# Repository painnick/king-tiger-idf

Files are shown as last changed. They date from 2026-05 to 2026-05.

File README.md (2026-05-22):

# RC 탱크 프로젝트

Bluepad32를 이용한 게임패드 조작 RC 탱크입니다. ESP32-IDF(v5.4.3) 기반으로 개발되었습니다.

## 주요 기능

- **게임패드 연결**: Bluepad32를 통한 블루투스 게임패드 연결 및 상태 LED/진동 피드백
- **트랙 제어**: 좌측 스틱 Y축(좌측 트랙), 우측 스틱 Y축(우측 트랙) 독립 제어 (DRV8833, MCPWM)
- **터렛 제어**: D-PAD 좌우로 터렛 회전 (DRV8833, MCPWM, 최대 속도 100% 듀티)
- **포 마운트 제어**: D-PAD 상하로 포신 상하 이동 (SG90 서보, 80~110도, 초당 10도)
- **포신 발사**: B 버튼 클릭 시 포신 반동(서보 0->60->0), LED 점등, 발사 효과음 및 게임패드 진동 발생 (트랙 후진 반동 200ms 동기화)
- **기관총 발사**: A 버튼 클릭 시 기관총 LED 깜빡임(500ms), 효과음 및 게임패드 진동 발생 (반응성 개선을 위해 지연 시간 300ms로 단축)
- **헤드라이트**: Y 버튼으로 헤드라이트 ON/OFF 토글
- **볼륨 조절**: L1 버튼으로 감소, R1 버튼으로 증가 (NVS 저장, 10-30 범위)
- **대기 상태 알림**: 게임패드 연결 전/해제 후에는 30초마다 엔진 IDLE 효과음을 1회 재생하여 상태 알림 (연결 중에는 IDLE 소리 중지)
- **설정 초기화**: Select + Start 버튼을 3초간 누르면 볼륨 설정 초기화 및 재시작

## 하드웨어 구성

### ESP32 핀 맵

| ESP32 핀 | 기능 | 설명 |
| :--- | :--- | :--- |
| **GPIO 4** | 후미등 LED | Backlight |
| **GPIO 5** | 헤드라이트 LED | Headlight (Y 버튼 토글) |
| **GPIO 13** | 포 마운트 서보 | SG90 서보 - 포신 상하 이동 (80~110도) |
| **GPIO 16** | 기관총 LED | MG LED (A 버튼 클릭 시 깜빡임) |
| **GPIO 17** | 포신 LED | Gun LED (B 버튼 클릭 시 점등) |
| **GPIO 21** | 터렛 IN2 | DRV8833 - 터렛 회전 (MCPWM) |
| **GPIO 22** | 터렛 IN1 | DRV8833 - 터렛 회전 (MCPWM) |
| **GPIO 23** | 사운드 TX | DFPlayer Mini UART TX |
| **GPIO 25** | 우측 트랙 IN2 | DRV8833 - 우측 트랙 (MCPWM) |
| **GPIO 26** | 좌측 트랙 IN2 | DRV8833 - 좌측 트랙 (MCPWM) |
| **GPIO 27** | 좌측 트랙 IN1 | DRV8833 - 좌측 트랙 (MCPWM) |
| **GPIO 32** | 포신 서보 | 포신 반동 (Recoil) 제어 |
| **GPIO 33** | 우측 트랙 IN1 | DRV8833 - 우측 트랙 (MCPWM) |

### 모터 드라이버 (DRV8833) 연결

#### 트랙 드라이버
- **AIN (27, 26)**: 좌측 트랙 모터 (MCPWM)
- **BIN (33, 25)**: 우측 트랙 모터 (MCPWM)

#### 터렛 드라이버
- **AIN (22, 21)**: 터렛 회전 모터 (MCPWM, 최대 속도 100% 듀티)

### 서보 모터
- **GPIO 32**: 포신 반동 서보 (B 버튼 시 0도 -> 60도 -> 0도 동작)
- **GPIO 13**: 포 마운트 서보 SG90 (D-PAD 상하, 80~110도 범위, 초기 90도)

### 사운드 모듈 (DFPlayer Mini)
- **TX (GPIO 23)**: 모듈의 RX 핀에 연결하여 UART 제어 (9600bps)
- **RX (NC)**: 현재 수신 핀이 연결되지 않아 모듈 피드백(재생 종료 알림 등) 대신 타이머/하드웨어 루프 명령어로 상태 제어

---

## 게임패드 조작법

| 조작 | 기능 | 상세 동작 |
| :--- | :--- | :--- |
| **좌측 스틱 Y** | 좌측 트랙 | 위(전진), 아래(후진) |
| **우측 스틱 Y** | 우측 트랙 | 위(전진), 아래(후진) |
| **D-PAD 좌/우** | 터렛 회전 | 좌우 회전 (MCPWM, 최대 속도) |
| **D-PAD 상/하** | 포 마운트 | 상하 이동 (SG90 서보, 80~110도) |
| **A 버튼** | 기관총 발사 | 효과음 재생 + MG LED 깜빡임 |
| **B 버튼** | 주포 발사 | 효과음 재생 + Gun LED 점등 + 서보 반동 |
| **Y 버튼** | 헤드라이트 | ON / OFF 토글 |
| **L1 / R1** | 볼륨 조절 | 볼륨 감소 / 증가 (NVS 자동 저장) |
| **Select + Start** | 시스템 초기화 | 3초간 입력 시 설정 초기화 및 재부팅 |

---

## 소프트웨어 구조

### 주요 컴포넌트 (`components/rctank/`)
- `rctank_motor`: MCPWM을 이용한 트랙 및 터렛 제어
- `rctank_servo`: LEDC를 이용한 포신 반동 서보 및 포 마운트(SG90) 서보 제어
- `rctank_led`: 각종 LED 상태 제어
- `rctank_dfplayer`: DFPlayer Mini 제어 및 효과음 재생
- `rctank_storage`: NVS를 이용한 볼륨 및 설정값 저장

### 플랫폼 로직 (`main/my_flatform.c`)
- Bluepad32 이벤트 핸들링 및 게임패드 입력 맵핑
- 발사 시퀀스 지연 보정 (Sound 재생 시점과 하드웨어 동작 동기화)

## 개발 환경 설정

1. **ESP-IDF v5.4.3** 설치
2. 프로젝트 루트의 `env.bat`를 실행하여 환경 변수 설정 (Windows)
3. `idf.py build` 명령으로 컴파일
4. `idf.py flash monitor` 명령으로 업로드 및 로그 확인

## 라이센스
MIT License

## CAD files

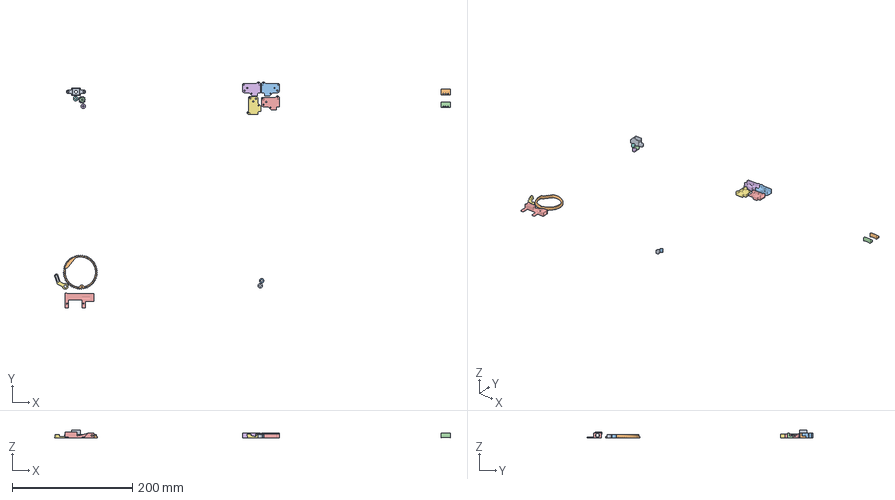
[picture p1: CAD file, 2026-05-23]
3dp/King Tiger.3mf
657.7 x 376.0 x 14.0 mm
Turret Motor Guide v3_1
Turret Gear
Sproket Spacer v3_1
Turret Combined.step
Cannon Guide
Turret Motor Guide v3_2
Mount Motor Horm.step
Turret Motor Guide v3_3
Sproket Spacer v3_2
Locker v1_1
Locker v1_2
Component1(Mirror)_1
Component1(Mirror)_2

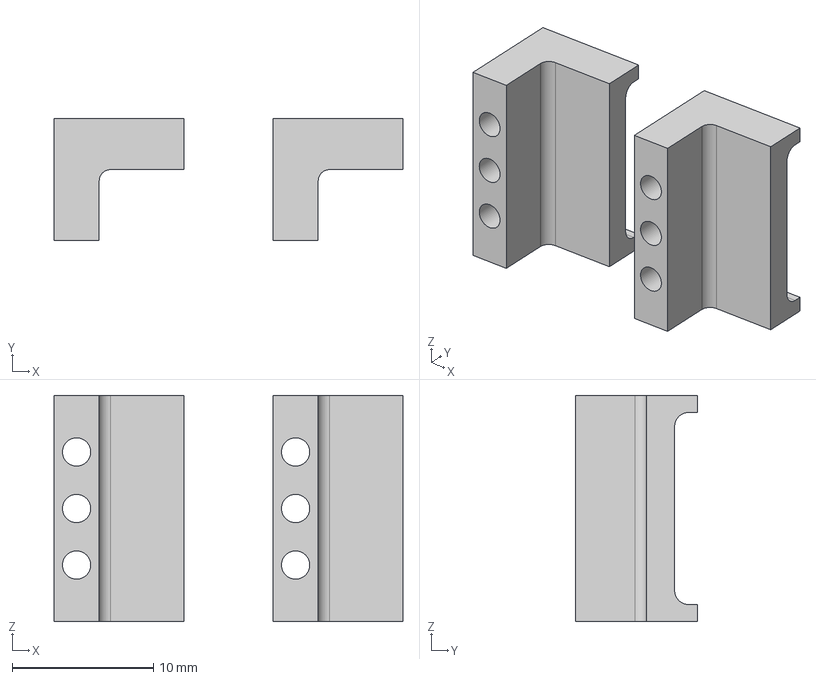
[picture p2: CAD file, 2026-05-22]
3dp/Locker.step
24.7 x 8.60 x 16.0 mm

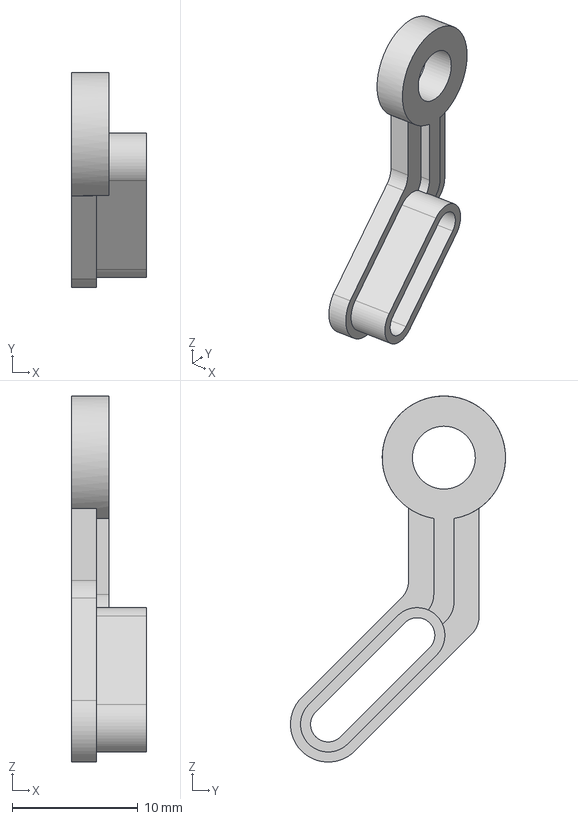
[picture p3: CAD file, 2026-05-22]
3dp/Mount Motor Horn.step
6.00 x 17.1 x 29.1 mm

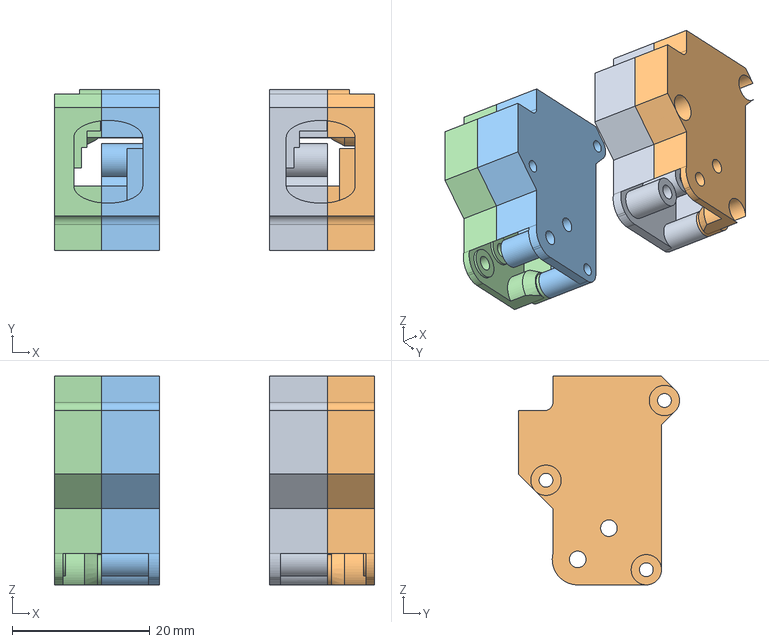
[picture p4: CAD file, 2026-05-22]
3dp/Gearbox2.step
46.4 x 23.4 x 30.3 mm
Component1(Mirror)

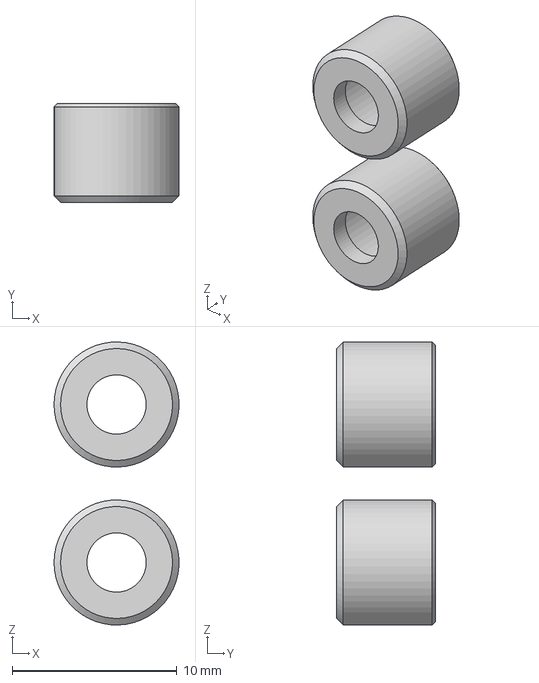
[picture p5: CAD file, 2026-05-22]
3dp/Sproket Spacer.step
7.59 x 6.00 x 17.2 mm

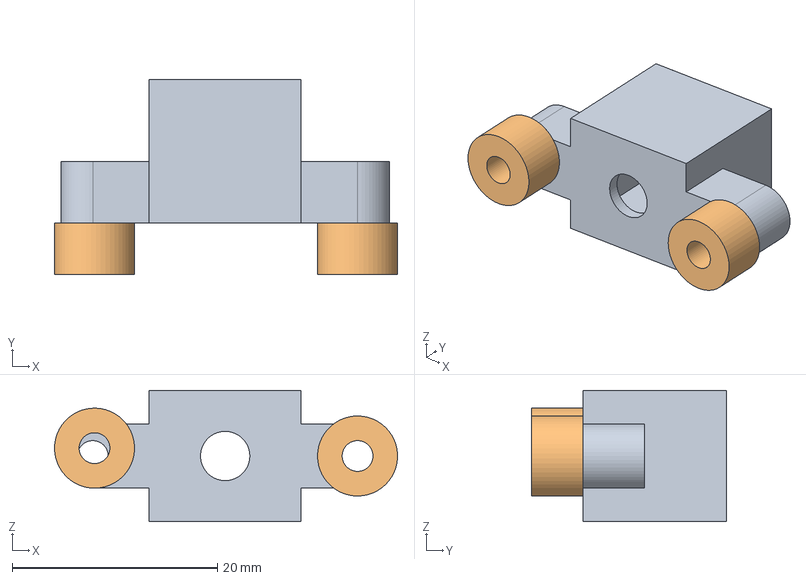
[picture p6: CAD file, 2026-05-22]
3dp/Turret Motor Guide.step
33.4 x 19.0 x 12.8 mm

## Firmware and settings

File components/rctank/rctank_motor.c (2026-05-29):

/**
 * @file rctank_motor.c
 * @brief RC Tank MCPWM 트랙/터렛 제어
 */
#include "rctank_motor.h"
#include "rctank_pins.h"

#include "driver/mcpwm_prelude.h"
#include "esp_log.h"
#include "esp_check.h"

#include "freertos/FreeRTOS.h"
#include "freertos/task.h"
#include "freertos/semphr.h"

static const char *TAG = "rctank_motor";

#define MCPWM_FREQ_HZ          (20000)
#define MCPWM_RESOLUTION_HZ   (1000000)
#define MCPWM_PERIOD_TICKS    (MCPWM_RESOLUTION_HZ / MCPWM_FREQ_HZ)

/* 스틱 범위 ±512 → 듀티 비율 (0~100%) */
#define AXIS_MAX              512

#define TRACK_DECEL_STEP 10  // 10ms 당 감속 단계 (실질 범위 448~512에서 약 640ms 내에 정지, 10배 스케일)
#define TRACK_ACCEL_STEP 6   // 10ms 당 가속 단계 (실질 범위 448~512에서 약 1000ms 내에 최대 속도 도달, 10배 스케일)
#define TRACK_MIN_SPEED  448 // 모터 구동을 개시하는 최소 기동 속도 오프셋 (0~512 범위 내)
#define TRACK_STICK_THRESHOLD 460  // 90% 스틱 경계값 (512 * 0.90)
#define TRACK_EXPO_THRESHOLD  178  // 90% 경계값에서의 모터 중간 속도 목표치 (최대 속도의 약 91%가 되도록 조정)

static mcpwm_cmpr_handle_t left_cmpr_a = NULL;
static mcpwm_cmpr_handle_t left_cmpr_b = NULL;
static mcpwm_cmpr_handle_t right_cmpr_a = NULL;
static mcpwm_cmpr_handle_t right_cmpr_b = NULL;
static mcpwm_cmpr_handle_t turret_cmpr_a = NULL;
static mcpwm_cmpr_handle_t turret_cmpr_b = NULL;

static mcpwm_timer_handle_t timer0 = NULL;

static volatile int32_t target_left_speed = 0;
static volatile int32_t target_right_speed = 0;
static int32_t current_left_speed = 0;
static int32_t current_right_speed = 0;

static SemaphoreHandle_t motor_mutex = NULL;
static TaskHandle_t motor_task_handle = NULL;

static void set_motor_duty(mcpwm_cmpr_handle_t cmpr_a, mcpwm_cmpr_handle_t cmpr_b, int32_t speed);

static void update_motor_speed(int32_t *current, int32_t target)
{
    int32_t cur = *current;
    if (cur == target) {
        return;
    }

    // 1. 0에서 기동할 때 최소 구동 속도(TRACK_MIN_SPEED * 10)로 즉시 점프
    if (cur == 0 && target != 0) {
        int32_t sign = (target > 0) ? 1 : -1;
        int32_t start_speed = sign * TRACK_MIN_SPEED * 10;
        
        int32_t target_abs = (target > 0) ? target : -target;
        // target 절대값이 최소 기동 속도 이하이면 즉시 target으로 설정 후 리턴
        if (target_abs <= TRACK_MIN_SPEED * 10) {
            *current = target;
            return;
        }
        cur = start_speed;
        *current = cur;
    }

    int32_t diff = target - cur;
    int32_t step;

    // Determine if we are accelerating or decelerating
    bool is_decelerating = false;
    
    if (cur > 0) {
        if (target < cur) {
            is_decelerating = true;
        }
    } else if (cur < 0) {
        if (target > cur) {
            is_decelerating = true;
        }
    } else {
        is_decelerating = false;
    }

    if (is_decelerating) {
        step = TRACK_DECEL_STEP;
    } else {
        step = TRACK_ACCEL_STEP;
    }

    if (diff > 0) {
        if (diff > step) {
            *current = cur + step;
        } else {
            *current = target;
        }
    } else {
        if (-diff > step) {
            *current = cur - step;
        } else {
            *current = target;
        }
    }

    // 2. 감속 정지 시 최소 구동 속도 이하로 떨어지면 웅웅거림 방지를 위해 즉시 0으로 정지
    if (target == 0) {
        int32_t cur_abs = (*current > 0) ? *current : -*current;
        if (cur_abs < TRACK_MIN_SPEED * 10) {
            *current = 0;
        }
    }
}

static void rctank_motor_update_task(void *pvParameters)
{
    TickType_t last_wake_time = xTaskGetTickCount();
    while (1) {
        if (motor_mutex && xSemaphoreTake(motor_mutex, portMAX_DELAY) == pdTRUE) {
            update_motor_speed(&current_left_speed, target_left_speed * 10);
            if (left_cmpr_a && left_cmpr_b) {
                set_motor_duty(left_cmpr_a, left_cmpr_b, current_left_speed / 10);
            }

            update_motor_speed(&current_right_speed, target_right_speed * 10);
            if (right_cmpr_a && right_cmpr_b) {
                set_motor_duty(right_cmpr_a, right_cmpr_b, current_right_speed / 10);
            }
            xSemaphoreGive(motor_mutex);
        }
        vTaskDelayUntil(&last_wake_time, pdMS_TO_TICKS(10));
    }
}

static void set_motor_duty(mcpwm_cmpr_handle_t cmpr_a, mcpwm_cmpr_handle_t cmpr_b, int32_t speed)
{
    uint32_t ticks;
    if (speed > 0) {
        ticks = ((uint32_t)speed * MCPWM_PERIOD_TICKS) / AXIS_MAX;
        if (ticks > MCPWM_PERIOD_TICKS) ticks = MCPWM_PERIOD_TICKS;
        ESP_ERROR_CHECK(mcpwm_comparator_set_compare_value(cmpr_a, ticks));
        ESP_ERROR_CHECK(mcpwm_comparator_set_compare_value(cmpr_b, 0));
    } else if (speed < 0) {
        ticks = ((uint32_t)(-speed) * MCPWM_PERIOD_TICKS) / AXIS_MAX;
        if (ticks > MCPWM_PERIOD_TICKS) ticks = MCPWM_PERIOD_TICKS;
        ESP_ERROR_CHECK(mcpwm_comparator_set_compare_value(cmpr_a, 0));
        ESP_ERROR_CHECK(mcpwm_comparator_set_compare_value(cmpr_b, ticks));
    } else {
        ESP_ERROR_CHECK(mcpwm_comparator_set_compare_value(cmpr_a, 0));
        ESP_ERROR_CHECK(mcpwm_comparator_set_compare_value(cmpr_b, 0));
    }
}
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

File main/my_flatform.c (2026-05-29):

// RC Tank platform - Bluepad32 + rctank (README.md 기능)
// C 함수 형태 구현 (Agent.md 코딩 규칙)

#include <string.h>

#include <platform/uni_platform.h>
#include <uni.h>
#include "controller/uni_controller.h"
#include "controller/uni_gamepad.h"

#include "driver/gpio.h"
#include "esp_timer.h"
#include "freertos/FreeRTOS.h"
#include "freertos/task.h"

#include "rctank.h"
#include "rctank_dfplayer.h"
#include "rctank_led.h"
#include "rctank_motor.h"
#include "rctank_servo.h"
#include "rctank_storage.h"

#define AXIS_DEADZONE 60
#define DEBOUNCE_MS 100
#define HEADLIGHT_DEBOUNCE_MS 400 /* 헤드라이트 토글 최소 간격 (둔감) */
#define GUN_PULL_MS 100           /* 1단계: 포신 당기기 지연 시간 */
#define GUN_TRACK_MS 200          /* 2단계: 트랙 반동 시간 */
#define GUN_RETURN_WAIT_MS 200    /* 3단계: 트랙 정지 후 포신 복구 대기 시간 */
#define GUN_DELAY_MS 400          /* 포신: MP3 재생 요청 후 서보/LED/럼블 지연 (DFPlayer 지연 보정) */
#define MG_FIRE_MS 500            /* 기관총 발사 시간 (LED 깜빡임) */
#define MG_LED_BLINK_MS 75        /* 기관총 LED 깜빡임 주기 */
#define MG_DELAY_MS 300           /* 기관총: MP3 재생 요청 후 LED/럼블 지연 */
#define TURRET_SPEED 511          /* 터렛 회전 속도 (최대, 100% 듀티) */
#define SELECT_START_HOLD_MS 3000
#define RECOIL_POWER 450 /* 반동 속도 */

typedef struct my_platform_instance_s {
    uni_gamepad_seat_t gamepad_seat;
} my_platform_instance_t;

static void trigger_event_on_gamepad(uni_hid_device_t* d);
static my_platform_instance_t* get_my_platform_instance(uni_hid_device_t* d);

static int64_t last_y_ms = 0;
static int64_t last_l1_ms = 0;
static int64_t last_r1_ms = 0;
static int64_t select_start_pressed_at = 0;
static int64_t recoil_end_time = 0; /* 반동 종료 시간 */
static uint8_t prev_buttons = 0;
static uint8_t prev_misc = 0;
static esp_timer_handle_t gun_timer = NULL;
static esp_timer_handle_t gun_delayed_start_timer = NULL;
static uni_hid_device_t* gun_delayed_device = NULL; /* 500ms 후 럼블용 */
static esp_timer_handle_t restart_timer = NULL;
static esp_timer_handle_t mg_blink_timer = NULL;
static esp_timer_handle_t mg_stop_timer = NULL;
static esp_timer_handle_t mg_delayed_start_timer = NULL;
static uni_hid_device_t* mg_delayed_device = NULL; /* 500ms 후 럼블용 */
static int mg_led_toggle = 0;

static esp_timer_handle_t gun_track_timer = NULL;
static esp_timer_handle_t gun_return_timer = NULL;
static esp_timer_handle_t gun_detach_timer = NULL;
static esp_timer_handle_t waiting_idle_timer = NULL; /* 연결 대기 중 30초 주기 알림용 */

static void waiting_idle_cb(void* arg) {
    (void)arg;
    rctank_dfplayer_play(RCTANK_DFPLAYER_TRACK_IDLE);
}

static void gun_detach_timer_cb(void* arg) {
    (void)arg;
    /* 서보 비활성화 (토크 해제) */
    rctank_servo_gun_enable(false);
}

static void gun_return_timer_cb(void* arg) {
    (void)arg;
    rctank_led_gun_set(0);
    rctank_servo_gun_set_degree(RCTANK_SERVO_GUN_DEG_REST);

    /* 복귀 완료 후 서보 끄기 (500ms 후) */
    esp_timer_stop(gun_detach_timer);
    esp_timer_start_once(gun_detach_timer, 500 * 1000);
}

static void gun_fire_timer_cb(void* arg) {
    (void)arg;
    /* 2단계 종료: 트랙 정지 */
    rctank_motor_left_track_set_immediate(0);
    rctank_motor_right_track_set_immediate(0);

    /* 3단계 시작: 포신 복구 지연 */
    esp_timer_start_once(gun_return_timer, GUN_RETURN_WAIT_MS * 1000);
}

static void gun_track_timer_cb(void* arg) {
    (void)arg;
    /* 2단계 시작: 트랙 밀기 */
    rctank_motor_left_track_set_immediate(-RECOIL_POWER);
    rctank_motor_right_track_set_immediate(-RECOIL_POWER);

    /* 트랙 정지 예약 */
    esp_timer_start_once(gun_timer, GUN_TRACK_MS * 1000);
}

/* 포신: MP3 재생 요청 후 GUN_DELAY_MS 지난 뒤 서보/LED/럼블 시작 (DFPlayer 지연 보정) */
static void gun_delayed_start_cb(void* arg) {
    (void)arg;

    /* 1단계 시작: 포신 당기기 */
    int64_t now_ms = esp_timer_get_time() / 1000;
    /* 리코일 제어권 잠금: 포신 당기기 + 트랙 밀기 시간 동안 */
    recoil_end_time = now_ms + GUN_PULL_MS + GUN_TRACK_MS;

    rctank_led_gun_set(1);
    rctank_servo_gun_set_degree(60);

    uni_hid_device_t* d = gun_delayed_device;
    gun_delayed_device = NULL;
    if (d != NULL && d->report_parser.play_dual_rumble != NULL)
        d->report_parser.play_dual_rumble(d, 0, 400, 150, 255);

    /* 2단계(트랙 밀기) 지연 시작 */
    esp_timer_stop(gun_track_timer);
    esp_timer_start_once(gun_track_timer, GUN_PULL_MS * 1000);
}

static void delayed_restart_cb(void* arg) {
    (void)arg;
    rctank_storage_erase_and_restart();
}

static void mg_blink_timer_cb(void* arg) {
    (void)arg;
    mg_led_toggle = !mg_led_toggle;
    rctank_led_mg_set(mg_led_toggle);
}

static void mg_stop_timer_cb(void* arg) {
    (void)arg;
    esp_timer_stop(mg_blink_timer);
    rctank_led_mg_set(0);
}

/* MP3 재생 요청 후 500ms 지난 뒤 LED 깜빡임 + 럼블 시작 (DFPlayer 지연 보정) */
static void mg_delayed_start_cb(void* arg) {
    (void)arg;
    uni_hid_device_t* d = mg_delayed_device;
    mg_delayed_device = NULL;
    if (d != NULL && d->report_parser.play_dual_rumble != NULL)
        d->report_parser.play_dual_rumble(d, 0, 300, 150, 200);
    esp_timer_stop(mg_blink_timer);
    esp_timer_stop(mg_stop_timer);
    mg_led_toggle = 0;
    rctank_led_mg_set(1);
    esp_timer_start_periodic(mg_blink_timer, MG_LED_BLINK_MS * 1000);
    esp_timer_start_once(mg_stop_timer, MG_FIRE_MS * 1000);
}
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

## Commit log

2026-04-11 ADD. 코드 생성
    [partitions.csv]
2026-04-11 feat: add pin configuration header and update project documentation
2026-04-12 feat: define hardware pin configuration and update project requirements
2026-04-28 FIX. PIN
2026-04-29 UPDATE. RCTank2_IDF 기반으로 수정
    [partitions.csv]
2026-05-01 FIX. 헤드 참조 누락
2026-05-01 UPDATE. 리코일 액션 및 효과음 처리 수정
    [my_flatform.c]
2026-05-22 UPDATE. 포신 상하 이동을 서보 모터로 변경
2026-05-22 FIX. 포신 상하 이동을 서보 모터로 변경
    [rctank_motor.c]
2026-05-22 CHANGE. 포신 좌우 회전을 MCPWM 방식으로 변경
2026-05-22 UPDATE. 포신 좌우 회전 속도를 상수로 변경
2026-05-22 ADD. 3D Printings
    [Gearbox2.step, King Tiger.3mf, Locker.step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]
2026-05-23 FIX. 3D Printings
    [King Tiger.3mf, Mount Motor Horn.step]
2026-05-29 UPDATE. 바로 정지하지 않고 다소 시간이 걸리도록 수정
    [my_flatform.c, rctank_motor.c]
2026-05-29 UPDATE. 비례제어 수정
2026-05-29 UPDATE. Rel/Debug 빌드 처리
